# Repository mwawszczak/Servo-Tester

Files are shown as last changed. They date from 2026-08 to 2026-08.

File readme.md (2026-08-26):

# RC Servo Tester — STM32G030K8Tx

A hand-held tester for RC hobby servos, and my first solo PCB project. The goal was to go through the whole process — schematic, PCB layout, SMD soldering, and firmware — from scratch, using KiCad and a bare-metal STM32 build.

## What it does

The tester lets you drive a servo manually or run it through a few automatic routines, without needing a full RC receiver/transmitter setup.

- **Manual mode** — a potentiometer sets the servo position live
- **Auto mode** — cycles through center, min, max, and a continuous sweep between the limits
- A mode switch toggles between manual and auto, a button steps through the auto sub-modes, and a start/stop button arms or disarms the PWM output
- Two LEDs show the current mode and whether the output is armed, through different blink patterns

## Hardware

The board is built around an STM32G030K8Tx, powered from micro USB through an AMS1117 3.3V regulator. It reads the potentiometer on an ADC input, generates the servo PWM signal (50Hz, 1–2ms pulse) from a hardware timer, and has three buttons with on-board RC filtering for hardware debounce. Programming and debugging go through a standard 4-pin SWD header. The design was kept deliberately simple — no protection circuitry beyond the basics — to keep the focus on finishing a working first revision rather than maximizing features.

## Firmware

Bare-metal C on the STM32 HAL, no RTOS. The firmware is split into small, self-contained modules — a mode state machine, button handling, an LED blink engine, potentiometer reading, and servo PWM control — each exposing a small public interface and keeping its internal state private. The main loop polls the buttons, feeds events into the state machine, updates the servo output and LEDs based on the current mode, and repeats — all non-blocking, driven off the system tick.

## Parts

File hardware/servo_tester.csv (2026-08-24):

Reference | Qty | Value | DNP | Exclude from BOM | Exclude from Board | Exclude from Simulation | Exclude from Position Files | Footprint | Datasheet
C1,C3,C4,C5,C6,C8,C10,C12 | 8 | 100n |  |  |  |  | ${EXCLUDE_FROM_POS_FILES} | Capacitor_SMD:C_0603_1608Metric_Pad1.08x0.95mm_HandSolder
C2,C9 | 2 | 22u |  |  |  |  | ${EXCLUDE_FROM_POS_FILES} | Capacitor_THT:CP_Radial_D4.0mm_P1.50mm
C7 | 1 | 10u |  |  |  |  | ${EXCLUDE_FROM_POS_FILES} | Capacitor_THT:CP_Radial_D4.0mm_P1.50mm
C11 | 1 | 4,7u |  |  |  |  | ${EXCLUDE_FROM_POS_FILES} | Capacitor_THT:CP_Radial_D4.0mm_P1.50mm
D1,D2,D3 | 3 | LED |  |  |  |  | ${EXCLUDE_FROM_POS_FILES} | Diode_SMD:D_1206_3216Metric_Pad1.42x1.75mm_HandSolder
F1 | 1 | 0,5A |  |  |  |  | ${EXCLUDE_FROM_POS_FILES} | Fuse:Fuse_1206_3216Metric_Pad1.42x1.75mm_HandSolder
J1 | 1 | USB_B_Micro |  |  |  |  | ${EXCLUDE_FROM_POS_FILES} | Connector_USB:USB_Micro-AB_Molex_47590-0001
J2 | 1 | SWD |  |  |  |  | ${EXCLUDE_FROM_POS_FILES} | Connector_PinHeader_2.54mm:PinHeader_1x04_P2.54mm_Vertical
J3,J4 | 2 | Conn_01x03_Pin |  |  |  |  | ${EXCLUDE_FROM_POS_FILES} | Connector_PinHeader_2.54mm:PinHeader_1x03_P2.54mm_Vertical
POT1 | 1 | MINMAX |  |  |  |  | ${EXCLUDE_FROM_POS_FILES} | Potentiometer_THT:Potentiometer_Alps_RK163_Single_Horizontal
R1,R2,R3,R4,R5,R6 | 6 | 1k |  |  |  |  | ${EXCLUDE_FROM_POS_FILES} | Resistor_SMD:R_0603_1608Metric_Pad0.98x0.95mm_HandSolder
SW1,SW2,SW3 | 3 | SW_Push |  |  |  |  | ${EXCLUDE_FROM_POS_FILES} | Button_Switch_SMD:SW_Push_1P1T_NO_E-Switch_TL3301NxxxxxG
TP1,TP6 | 2 | GND |  |  |  |  | ${EXCLUDE_FROM_POS_FILES} | TestPoint:TestPoint_THTPad_D1.5mm_Drill0.7mm
TP2 | 1 | 5V |  |  |  |  | ${EXCLUDE_FROM_POS_FILES} | TestPoint:TestPoint_THTPad_D1.5mm_Drill0.7mm
TP3 | 1 | 3V3 |  |  |  |  | ${EXCLUDE_FROM_POS_FILES} | TestPoint:TestPoint_THTPad_D1.5mm_Drill0.7mm
TP4 | 1 | ADC |  |  |  |  | ${EXCLUDE_FROM_POS_FILES} | TestPoint:TestPoint_THTPad_D1.5mm_Drill0.7mm
TP5 | 1 | PWM |  |  |  |  | ${EXCLUDE_FROM_POS_FILES} | TestPoint:TestPoint_THTPad_D1.5mm_Drill0.7mm
TP7,TP8 | 2 | Reserved |  |  |  |  | ${EXCLUDE_FROM_POS_FILES} | TestPoint:TestPoint_Pad_D1.0mm
U1 | 1 | AMS1117-3.3 |  |  |  |  | ${EXCLUDE_FROM_POS_FILES} | Package_TO_SOT_SMD:SOT-223-3_TabPin2 | http://www.advanced-monolithic.com/pdf/ds1117.pdf
U2 | 1 | STM32G030K8Tx |  |  |  |  | ${EXCLUDE_FROM_POS_FILES} | Package_QFP:LQFP-32_7x7mm_P0.8mm | https://www.st.com/resource/en/datasheet/stm32g030k8.pdf

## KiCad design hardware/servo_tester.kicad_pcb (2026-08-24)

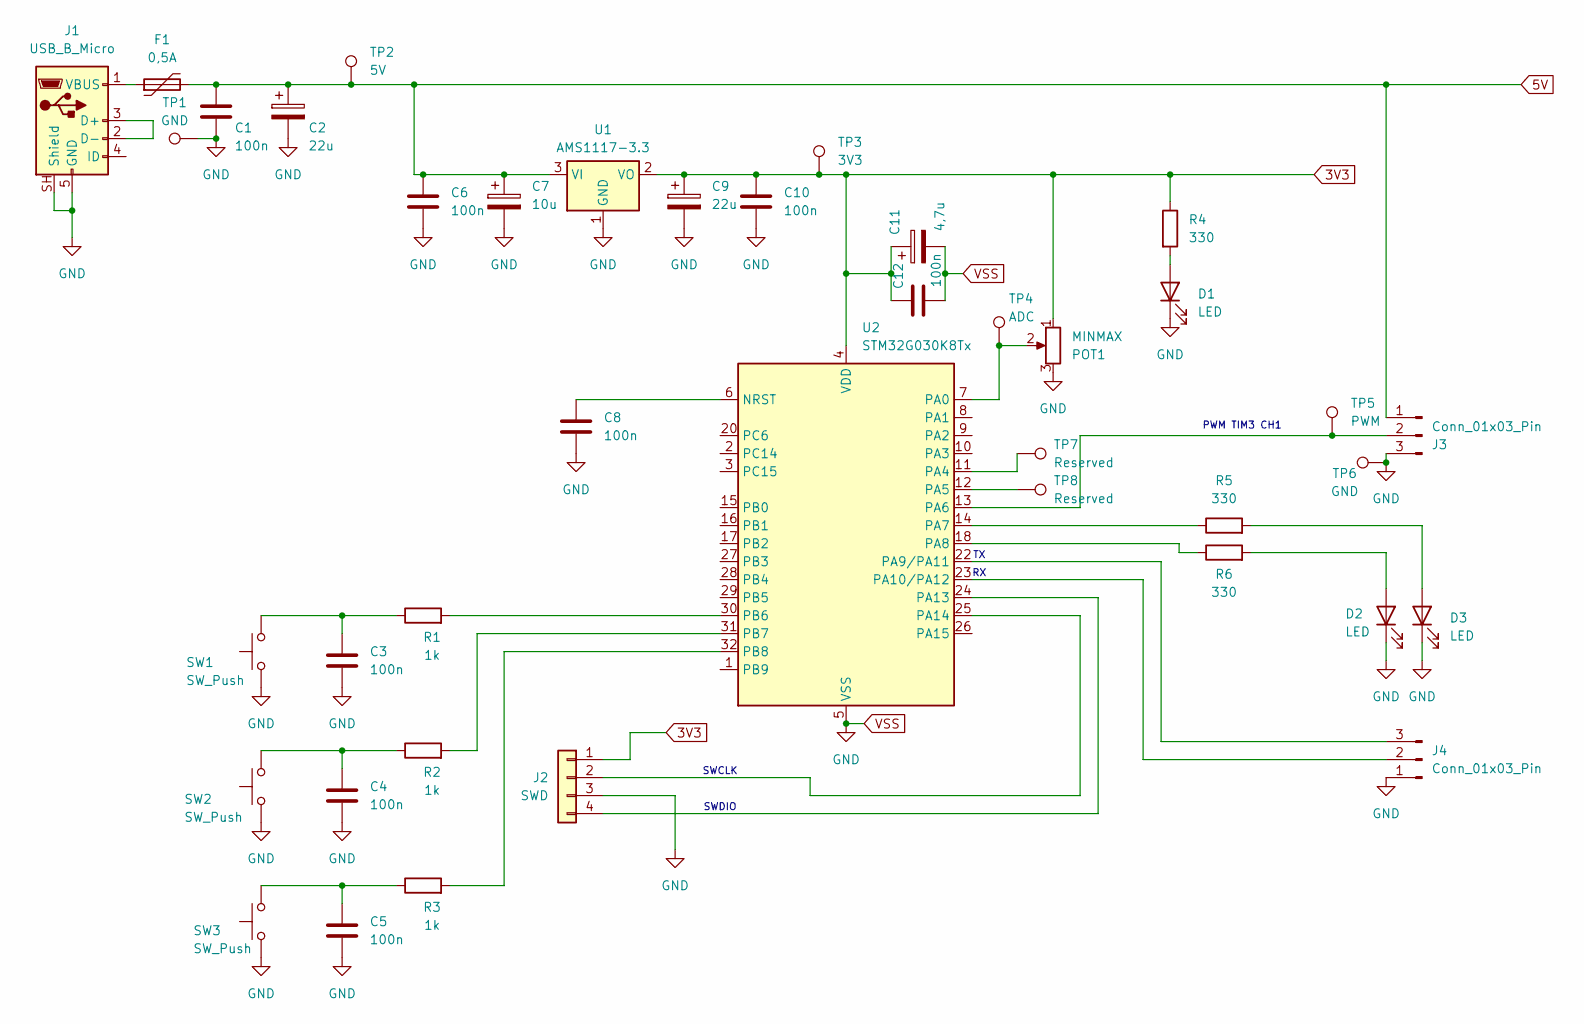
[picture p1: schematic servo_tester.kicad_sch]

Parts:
C1, C3, C4, C5, C6, C8, C10, C12: 100n; C_0603_1608Metric_Pad1.08x0.95mm_HandSolder
C2, C9: 22u; CP_Radial_D4.0mm_P1.50mm
C7: 10u; CP_Radial_D4.0mm_P1.50mm
C11: 4,7u; CP_Radial_D4.0mm_P1.50mm
D1, D2, D3: LED; D_1206_3216Metric_Pad1.42x1.75mm_HandSolder
F1: 0,5A; Fuse_1206_3216Metric_Pad1.42x1.75mm_HandSolder
J1: USB_B_Micro; USB_Micro-AB_Molex_47590-0001
J2: SWD; PinHeader_1x04_P2.54mm_Vertical
J3, J4: Conn_01x03_Pin; PinHeader_1x03_P2.54mm_Vertical
POT1: MINMAX; Potentiometer_Alps_RK163_Single_Horizontal
R1, R2, R3: 1k; R_0603_1608Metric_Pad0.98x0.95mm_HandSolder
R4, R5, R6: 330; R_0603_1608Metric_Pad0.98x0.95mm_HandSolder
SW1, SW2, SW3: SW_Push; SW_Push_1P1T_NO_E-Switch_TL3301NxxxxxG
TP1, TP6: GND; TestPoint_THTPad_D1.5mm_Drill0.7mm
TP2: 5V; TestPoint_THTPad_D1.5mm_Drill0.7mm
TP3: 3V3; TestPoint_THTPad_D1.5mm_Drill0.7mm
TP4: ADC; TestPoint_THTPad_D1.5mm_Drill0.7mm
TP5: PWM; TestPoint_THTPad_D1.5mm_Drill0.7mm
TP7, TP8: Reserved; TestPoint_Pad_D1.0mm
U1: AMS1117-3.3; SOT-223-3_TabPin2
U2: STM32G030K8Tx; LQFP-32_7x7mm_P0.8mm

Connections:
3V3: C9.1, C10.1, C11.1, C12.1, J2.1, POT1.1, R4.1, TP3.1 (1_1), U1.2 (VO), U2.4 (VDD)
5V: C1.1, C2.1, C6.1, C7.1, F1.2, J3.1, TP2.1 (1_1), U1.3 (VI)
unnamed: C3.1, R1.1, SW1.2
unnamed: C4.1, R2.1, SW2.2
unnamed: C5.1, R3.1, SW3.2
unnamed: D1.2 (A), R4.2
unnamed: D2.2 (A), R6.2
unnamed: D3.2 (A), R5.2
unnamed: J1.2 (D-), J1.3 (D+)
unnamed: F1.1, J1.1 (VBUS)
unnamed: J2.2, U2.25 (PA14)
unnamed: J2.4, U2.24 (PA13)
unnamed: J3.2, TP5.1 (1_1), U2.13 (PA6)
unnamed: J4.2, U2.23 (PA10/PA12)
unnamed: J4.3, U2.22 (PA9/PA11)
unnamed: C8.1, U2.6 (NRST)
unnamed: POT1.2, TP4.1 (1_1), U2.7 (PA0)
unnamed: TP7.1 (1_1), U2.11 (PA4)
unnamed: TP8.1 (1_1), U2.12 (PA5)
unnamed: R5.1, U2.14 (PA7)
unnamed: R6.1, U2.18 (PA8)
unnamed: R1.2, U2.30 (PB6)
unnamed: R2.2, U2.31 (PB7)
unnamed: R3.2, U2.32 (PB8)
VSS: C1.2, C2.2, C3.2, C4.2, C5.2, C6.2, C7.2, C8.2, C9.2, C10.2, C11.2, C12.2, D1.1 (K), D2.1 (K), D3.1 (K), J1.5 (GND), J1.SH (Shield), J2.3, J3.3, J4.1, POT1.3, SW1.1, SW2.1, SW3.1, TP1.1 (1_1), TP6.1 (1_1), U1.1 (GND), U2.5 (VSS)

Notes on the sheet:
SWCLK
SWDIO
PWM TIM3 CH1

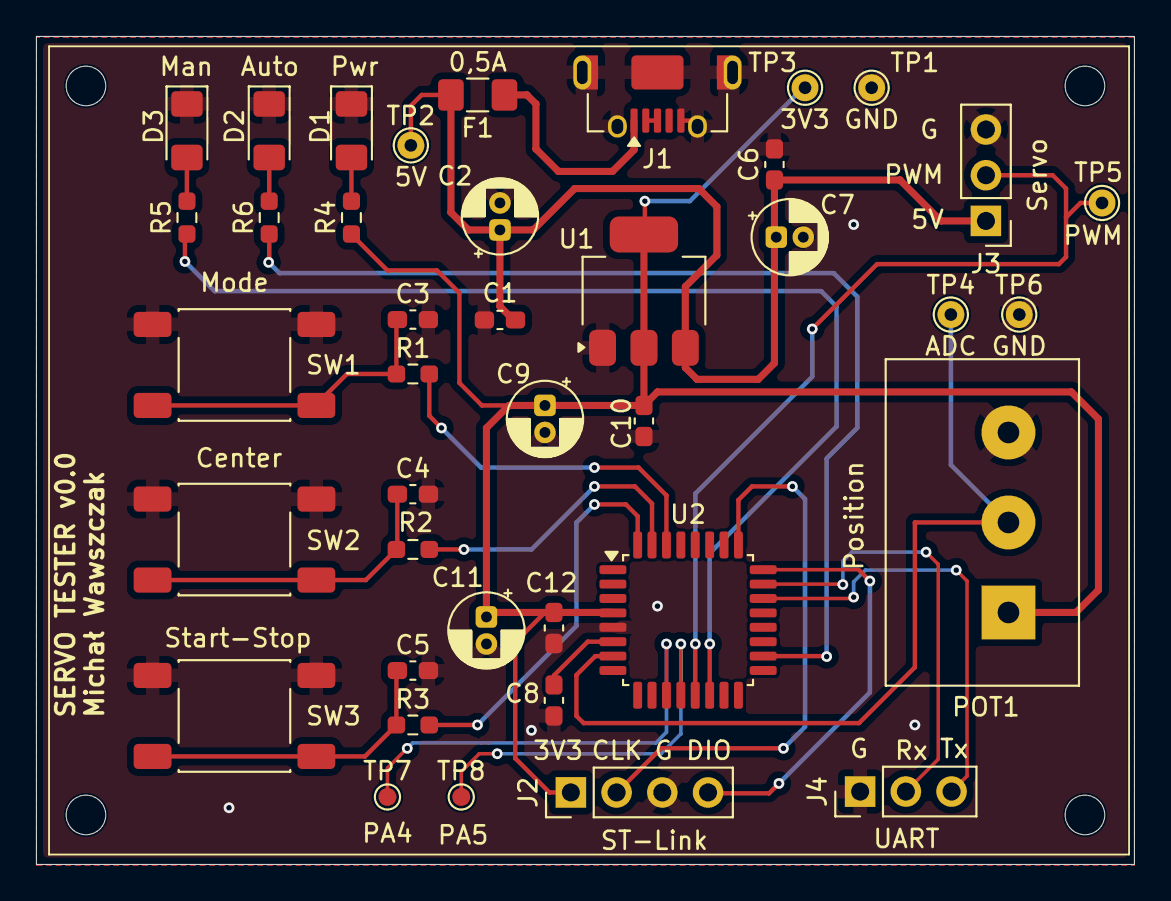
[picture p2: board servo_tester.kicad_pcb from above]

Board: 2 copper layers, 61.0 x 46.0 mm, 40 parts (0 on the bottom side), 25 nets.

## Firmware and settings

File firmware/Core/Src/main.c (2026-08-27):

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
/* Includes ------------------------------------------------------------------*/
#include "main.h"
#include "adc.h"
#include "dma.h"
#include "tim.h"
#include "usart.h"
#include "gpio.h"

/* USER CODE BEGIN Includes */
#include "mode_fsm.h"
#include "buttons.h"
#include "led.h"
#include "pos_input.h"
#include "servo.h"
#include <stdbool.h>
/* USER CODE END Includes */

/* USER CODE BEGIN PTD */
typedef struct {
	led_pattern_t led_auto_pattern;
	led_pattern_t led_manual_pattern;
} led_pattern_pair_t;


/* USER CODE END PTD */


/* USER CODE BEGIN PV */
static const led_pattern_pair_t led_table[SERVO_MODE_COUNT][ARM_STATUS_COUNT] = {
		[SERVO_MODE_MANUAL] = {
				[ARMED] = {
						.led_auto_pattern = LED_OFF,
						.led_manual_pattern = LED_ON
				},
				[DISARMED] = {
						.led_auto_pattern = LED_OFF,
						.led_manual_pattern = LED_SLOW_BLINK
				}
		},
		[SERVO_MODE_AUTO_CENTER] = {
				[ARMED] = {
						.led_auto_pattern = LED_ON,
						.led_manual_pattern = LED_OFF
				},
				[DISARMED] = {
						.led_auto_pattern = LED_SLOW_BLINK,
						.led_manual_pattern = LED_OFF
				}
		},
		[SERVO_MODE_AUTO_MIN] = {
				[ARMED] = {
						.led_auto_pattern = LED_FAST_BLINK_x1,
						.led_manual_pattern = LED_OFF
				},
				[DISARMED] = {
						.led_auto_pattern = LED_HALF_FAST_BLINK_x1,
						.led_manual_pattern = LED_OFF
				}
			},
		[SERVO_MODE_AUTO_MAX] = {
				[ARMED] = {
						.led_auto_pattern = LED_FAST_BLINK_x2,
						.led_manual_pattern = LED_OFF
				},
				[DISARMED] = {
						.led_auto_pattern = LED_HALF_FAST_BLINK_x2,
						.led_manual_pattern = LED_OFF
				}
		},
		[SERVO_MODE_AUTO_SWEEP] = {
				[ARMED] = {
						.led_auto_pattern = LED_FAST_BLINK,
						.led_manual_pattern = LED_OFF
				},
				[DISARMED] = {
						.led_auto_pattern = LED_HALF_FAST_BLINK,
						.led_manual_pattern = LED_OFF
				}
		}
};
/* USER CODE END PV */

void SystemClock_Config(void);
/**
  * @brief  The application entry point.
  * @retval int
  */
int main(void)
{

  /* MCU Configuration--------------------------------------------------------*/

  /* Reset of all peripherals, Initializes the Flash interface and the Systick. */
  HAL_Init();

  /* Configure the system clock */
  SystemClock_Config();

  /* Initialize all configured peripherals */
  MX_GPIO_Init();
  MX_DMA_Init();
  MX_ADC1_Init();
  MX_TIM3_Init();
  MX_USART1_UART_Init();
  /* USER CODE BEGIN 2 */
  fsm_init();
  arm_status_t arm_status = fsm_is_armed();
  arm_status_t arm_status_previous = arm_status;
  servo_mode_t current_mode = fsm_get_mode();
  servo_mode_t previous_mode = current_mode;

  led_pattern_select(LED_MANUAL, led_table[current_mode][arm_status].led_manual_pattern);
  led_pattern_select(LED_AUTO, led_table[current_mode][arm_status].led_auto_pattern);

  position_input_init();

  /* USER CODE END 2 */

  /* Infinite loop */
  /* USER CODE BEGIN WHILE */
  while (1)
  {
	  if (button_get(BTN_MODE)) fsm_handle_event(EVT_SW_MODE);
	  if (button_get(BTN_CENTER)) fsm_handle_event(EVT_SW_CENTER);
	  if (button_get(BTN_ARM)) fsm_handle_event(EVT_SW_ARM);

	  arm_status = fsm_is_armed();
	  current_mode = fsm_get_mode();


	  bool mode_changed;
	  bool arm_changed;

	  mode_changed = (current_mode != previous_mode);
	  previous_mode = current_mode;

	  arm_changed = (arm_status != arm_status_previous);
	  arm_status_previous = arm_status;

	  // LED pattern select, only once in loop (it resets time position)
	  if (arm_changed || mode_changed) {
		  led_pattern_select(LED_MANUAL, led_table[current_mode][arm_status].led_manual_pattern);
		  led_pattern_select(LED_AUTO, led_table[current_mode][arm_status].led_auto_pattern);
	  }
	  if (arm_status == ARMED) {

		  switch(current_mode) {
				  case SERVO_MODE_MANUAL:
					  servo_position_set(position_input_get());
					  break;
				  case SERVO_MODE_AUTO_CENTER:
					  servo_center();
					  break;
				  case SERVO_MODE_AUTO_MIN:
					  servo_min();
					  break;
				  case SERVO_MODE_AUTO_MAX:
					  servo_max();
					  break;
				  case SERVO_MODE_AUTO_SWEEP:
					  servo_sweep();
					  break;
				  default:
					  break;
			  }
	  }


	  if (arm_changed) {
		  if (arm_status == ARMED) servo_arm();
		  else servo_disarm();
	  }


	  led_update();

    /* USER CODE END WHILE */

    /* USER CODE BEGIN 3 */
  }
  /* USER CODE END 3 */
}

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


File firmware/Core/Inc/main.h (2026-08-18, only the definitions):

#define LED_MODE_MANUAL_Pin GPIO_PIN_7
#define LED_MODE_MANUAL_GPIO_Port GPIOA
#define LED_MODE_AUTO_Pin GPIO_PIN_8
#define LED_MODE_AUTO_GPIO_Port GPIOA
#define SW_MODE_Pin GPIO_PIN_6
#define SW_MODE_GPIO_Port GPIOB
#define SW_CENTER_Pin GPIO_PIN_7
#define SW_CENTER_GPIO_Port GPIOB
#define SW_ARM_Pin GPIO_PIN_8
#define SW_ARM_GPIO_Port GPIOB

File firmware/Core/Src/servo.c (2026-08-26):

#include <servo.h>
#include <stdlib.h>
#include "tim.h"


static const uint16_t servo_position_center = 1500;
static const uint16_t servo_position_min = 1000;
static const uint16_t servo_position_max = 2000;
static const uint16_t step = 20;
static const uint16_t time_per_step = 20;

static servo_state_t servo = {
		.time_ms = 0,
		.current_position = servo_position_center,
		.direction = UP,
		.target_position_reached = false
};

servo_error_t servo_position_set(uint16_t servo_position) {

	int diff;
	if ((servo_position < servo_position_min) || (servo_position > servo_position_max))
		return SERVO_POSITION_ERROR;

	// check if current_position is equal to target position
	if (servo.current_position != servo_position) {
		servo.target_position_reached = false;
		// ease in/out
		if ((HAL_GetTick() - servo.time_ms) > time_per_step) {
			servo.time_ms = HAL_GetTick();
			diff = servo.current_position - servo_position;
			if (diff > 0) {
				if (diff > step) servo.current_position -= step;
				// if current difference is less then setp -
				// use diff as last step to prevent overshooting
				else servo.current_position -= diff;
			}
			else {
				if (abs(diff) > step )servo.current_position += step;
				else servo.current_position += abs(diff);
			}
		}
	__HAL_TIM_SET_COMPARE(&htim3, TIM_CHANNEL_1, servo.current_position);
	}
	else servo.target_position_reached = true;
	return SERVO_NO_ERROR;
}

void servo_init(void) {
	// set servo in center position and populate servo variable with real values
	servo_position_set(servo_position_center);
}

void servo_center(void) {
	servo_position_set(servo_position_center);
}

void servo_min(void) {
	servo_position_set(servo_position_min);
}

void servo_max(void) {
	servo_position_set(servo_position_max);
}

void servo_sweep(void) {
		static int srv_pos = 1000;

	if (servo.target_position_reached) {
		if (servo.direction ==  UP) {
			srv_pos += step;
			if (srv_pos >= servo_position_max) servo.direction = DOWN;
		}
		else {
			srv_pos -= step;
			if (srv_pos <= servo_position_min) servo.direction = UP;
		}
	}
	servo_position_set(srv_pos);
}

void servo_arm(void){
	HAL_TIM_PWM_Start(&htim3, TIM_CHANNEL_1);
}

void servo_disarm(void) {
	HAL_TIM_PWM_Stop(&htim3, TIM_CHANNEL_1);
}

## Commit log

2026-08-18 general: unsused drivers deleted
2026-08-18 Buttons: basic functions for buttons added
2026-08-18 Buttons: added stucture for button state, poll/pressed functions refactored to reflect the change
2026-08-18 general: SW_START_STOP pin label changed to SW_ARM
2026-08-18 Buttons: table of structures added for all buttons, poll and pressed functions changed to static and button_get() added for use in main.c
2026-08-19 LED: basic data structure for blink engine created
2026-08-20 LED: led_on, led_off, led_update added
2026-08-20 LED: led_pattern_select() with args validation
2026-08-21 PWM: timer configuration changed
2026-08-21 PWM: basic functions to generate 50Hz PWM signals
2026-08-24 LED: fixed bug in pattern select - was direct value insted of table index
    [led.c]
2026-08-24 main: included buttons.h and led.h + basic test for hardware
2026-08-24 PWM: servo_position() and servo_sweep() modified
2026-08-24 HARDWARE: added KiCad PCB files + modified .gitignore
    [servo_tester.csv, servo_tester.kicad_pcb, servo_tester.kicad_sch]
2026-08-24 PWM: added ease in/out for servo position and structure for servo
2026-08-25 general: ADC1 configuration changed to use DMA
2026-08-25 POSITION INPUT: added module pos_input to init ADC1, read and convert readings to PWM timing (1000 - 2000 us)
2026-08-26 LED: NO_ERROR chaged to LED_NO_ERROR in led_error_t
2026-08-26 FSM: added arm_status_t and modified functions using bool arm status
2026-08-26 PWM: SERVO_NO_ERROR chaged to SERVO_NO_ERROR in servo_error_t
2026-08-27 MAIN: bug fix - changing position while disarmed caused rapid position changes after arming again
    [main.c]
2026-08-27 LED: added patterns (HALF_) to use display different auto sub-modes when not armed

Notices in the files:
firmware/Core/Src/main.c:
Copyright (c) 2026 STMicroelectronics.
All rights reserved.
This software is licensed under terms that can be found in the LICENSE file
